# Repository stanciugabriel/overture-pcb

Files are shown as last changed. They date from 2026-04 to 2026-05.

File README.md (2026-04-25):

# Overture PCB

Overture is a custom ESP32-C6 control board designed to drive a NEMA 17 stepper motor while handling NFC reading, a small display, and physical user inputs. Everything is powered through a single USB-C Power Delivery connection.

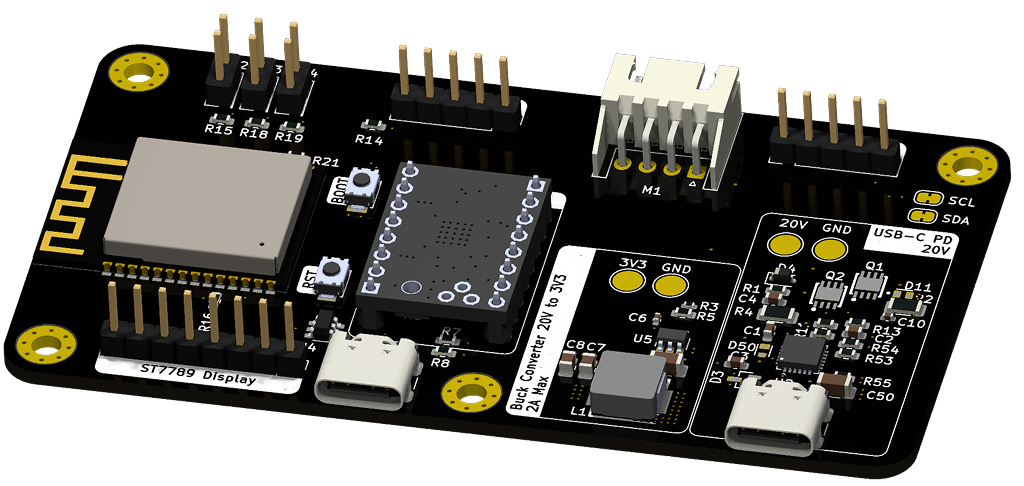
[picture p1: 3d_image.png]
3d image


## Hardware Specs

* **Microcontroller:** ESP32-C6-WROOM-1
* **Motor Driver:** TMC2208/TMC2209 setup driving a JST-XH port, sized for a NEMA 17 stepper.
* **Peripheral Headers:** Broken out pins for an ST7789 TFT screen, a PN532 NFC module, 3 push buttons, and a rotary encoder.
* **Power Delivery:** Uses an STUSB4500 PD controller to negotiate 20V directly from a USB-C wall adapter.
* **Power Regulation:** A TPS54308DDCT buck converter steps the 20V down to 3.3V (up to 2A max) to power the ESP32 and logic peripherals.
* **Programming:** Features a secondary USB-C port dedicated strictly to flashing and serial output.

## Power and Flashing

The board uses a dual USB-C port design to separate power and data. 

To power the motor and board, plug a compatible USB-C PD charger into the main power port. The STUSB4500 handles the 20V negotiation automatically. 

To flash the ESP32, use the secondary USB-C port. Note that the primary power port does not route data lines to the ESP32 and will not show up as a COM port on your machine.

## Exports

The exports folder contains all the file for production:
* hw1-bom.csv - is the Bill of Materials (formatted for JLCPCB)
* hw1-top-pos.csv - is the Components Position File for PCB-A (formatted for JLCPCB)
* Gerber_Archived.zip - has all the Gerber and Drill files needed for production

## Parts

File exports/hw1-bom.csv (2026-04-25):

Value | Reference | Footprint | LCSC
100nF | C6,C10 | Capacitor_SMD:C_0402_1005Metric | C307331
1uF | C1,C2,C3,C4 | Capacitor_SMD:C_0603_1608Metric | C5199872
33uF | C7,C8 | Capacitor_SMD:C_0805_2012Metric | C342635
6.8uF | C5 | Capacitor_SMD:C_1206_3216Metric | C92797
4.7uf | C50 | Capacitor_SMD:C_1206_3216Metric | C29823
Stepper_Motor | M1 | Connector_JST:JST_XH_S4B-XH-A_1x04_P2.50mm_Horizontal | C5361047
~ | PN532-Module1 | Connector_PinHeader_2.54mm:PinHeader_1x05_P2.54mm_Vertical
RotaryEncoder_Switch | SW1 | Connector_PinHeader_2.54mm:PinHeader_1x05_P2.54mm_Vertical
~ | ST7789-Display1 | Connector_PinHeader_2.54mm:PinHeader_1x08_P2.54mm_Vertical
SW_Back | SW2 | Connector_PinHeader_2.54mm:PinHeader_2x01_P2.54mm_Vertical
SW_Bolus | SW3 | Connector_PinHeader_2.54mm:PinHeader_2x01_P2.54mm_Vertical
SW_Settings | SW4 | Connector_PinHeader_2.54mm:PinHeader_2x01_P2.54mm_Vertical
Schottky | D4 | Diode_SMD:D_SOD-323 | C7502694
STL6P3LLH6 | Q1,Q2 | hw1_footprint:mosfetty | C49452349
ESP32-C6-WROOM-1 | U6 | hw1_footprint:ESP32-C6-WROOM-1_edit | C5366877
3.3uH | L1 | hw1_footprint:IND-SMD_L7.2-W6.6_GPSR07X0 | C5189747
STUSB4500QTR | U2 | hw1_footprint:QFN-24-1EP_4x4mm_P0.5mm_EP2.65x2.65mm | C2678061
ESDA25W | D3 | hw1_footprint:SOT65P210X110-3N | C2935152
TPS54308DDCT | U5 | hw1_footprint:SOT95P280X110-6N | C168839
SW_Push | SW5,SW6 | hw1_footprint:SW_TS-1088-AR02016 | C720477
~ | U1 | hw1_footprint:TMC2208_edit
ESDA25P35-1U1M | D11,D50 | hw1_footprint:TVS_ESDA25P35-1U1M | C1974707
~ | JP5,JP6 | Jumper:SolderJumper-2_P1.3mm_Bridged_RoundedPad1.0x1.5mm
MountingHole_Pad | H1,H2,H3,H4 | MountingHole:MountingHole_3mm_Pad_Via
USBLC6-2SC6 | U4 | Package_TO_SOT_SMD:SOT-23-6 | C7519
100k | R3 | Resistor_SMD:R_0402_1005Metric | C25741
470 | R1 | Resistor_SMD:R_0603_1608Metric | C23179
22k | R5 | Resistor_SMD:R_0603_1608Metric | C31850
10k | R6,R14,R15,R16,R18,R19 | Resistor_SMD:R_0603_1608Metric | C25804
5.1k | R7,R8 | Resistor_SMD:R_0603_1608Metric | C23186
100K | R10,R55 | Resistor_SMD:R_0603_1608Metric | C25803
22K | R11 | Resistor_SMD:R_0603_1608Metric | C31850
100 | R13 | Resistor_SMD:R_0603_1608Metric | C22775
4.7k | R21 | Resistor_SMD:R_0603_1608Metric | C23162
100k | R53,R54 | Resistor_SMD:R_0603_1608Metric | C25803
1k | R2,R4 | Resistor_SMD:R_1206_3216Metric | C4410
TestPoint | TP1,TP4,TP_3V3,TP_20V1 | TestPoint:TestPoint_Pad_D3.0mm
USB_C_Receptacle_USB2.0_16P | J1,J2 | USB_C_Receptacle_GCT_USB4105-xx-A_16P_TopMnt_Horizontal | C2765186

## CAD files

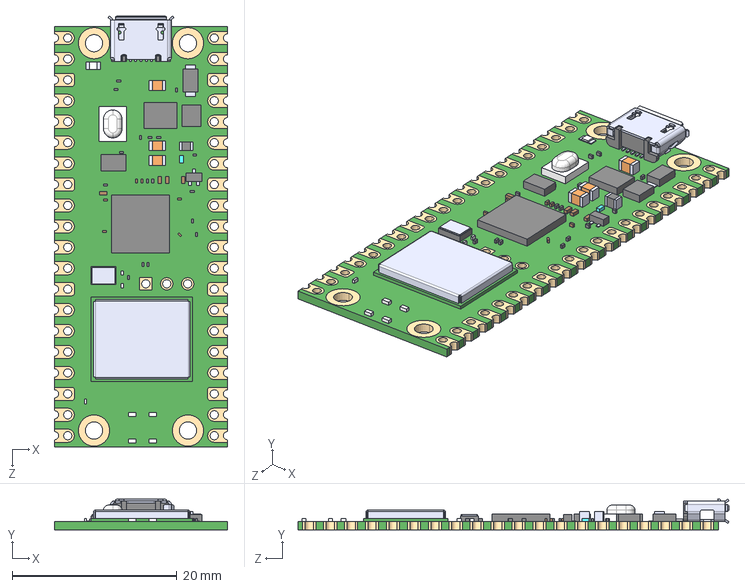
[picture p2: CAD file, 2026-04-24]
step-files/RASPBERRY_PI_PICO_W.step
21.0 x 3.73 x 52.3 mm

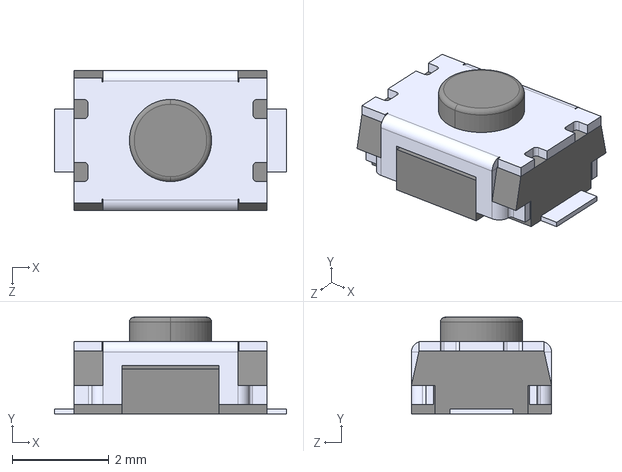
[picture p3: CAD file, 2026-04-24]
step-files/TS-1088-AR02016.step
4.80 x 2.00 x 2.90 mm

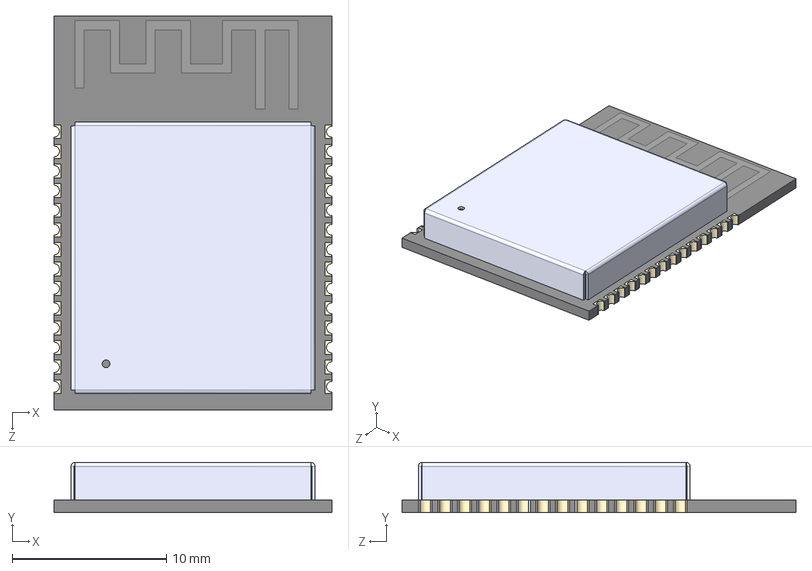
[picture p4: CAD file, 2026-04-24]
step-files/ESP32-C6-WROOM-1-N8.step
18.0 x 3.25 x 25.5 mm

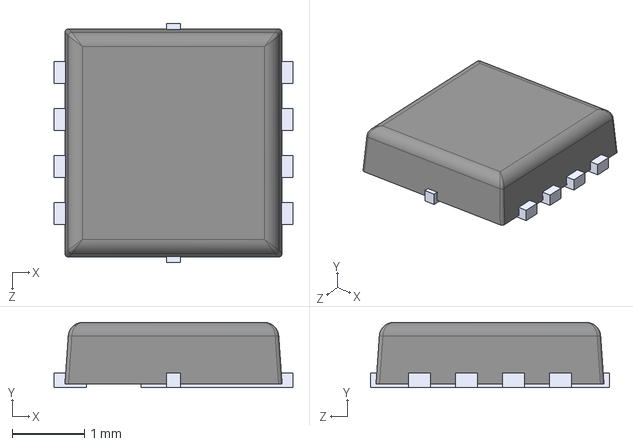
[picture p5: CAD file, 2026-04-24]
step-files/STL6P3LLH6.step
3.30 x 0.9 x 3.30 mm

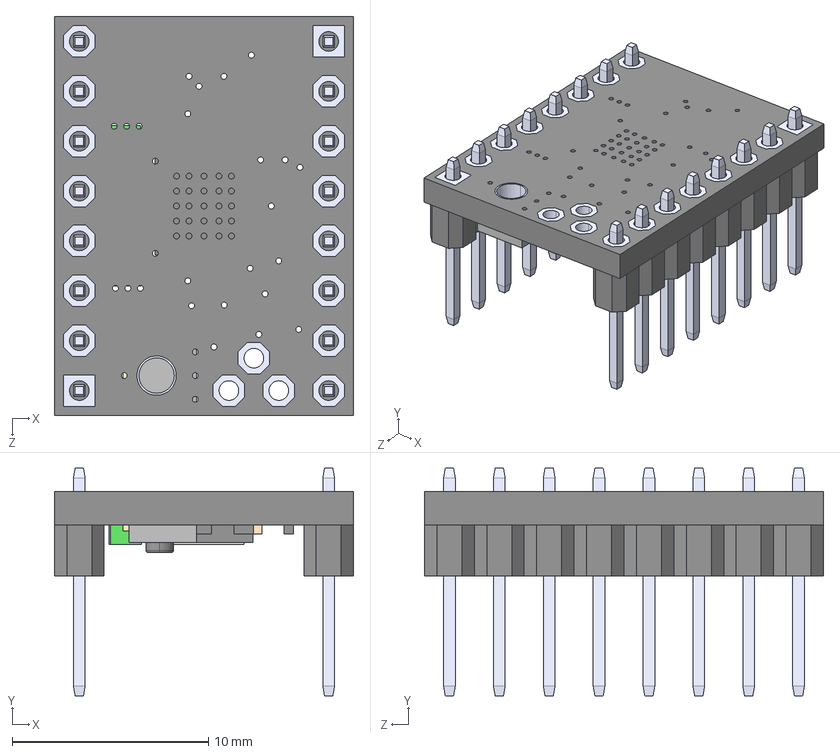
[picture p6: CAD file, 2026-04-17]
step-files/TMC2209_SILENTSTEPSTICK.step
15.2 x 11.6 x 20.3 mm

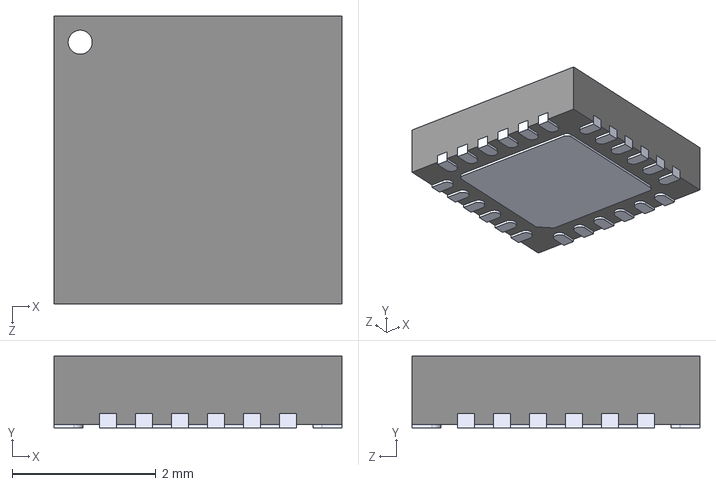
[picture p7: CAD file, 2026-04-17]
step-files/STUSB4500QTR.step
4.00 x 1.00 x 4.00 mm

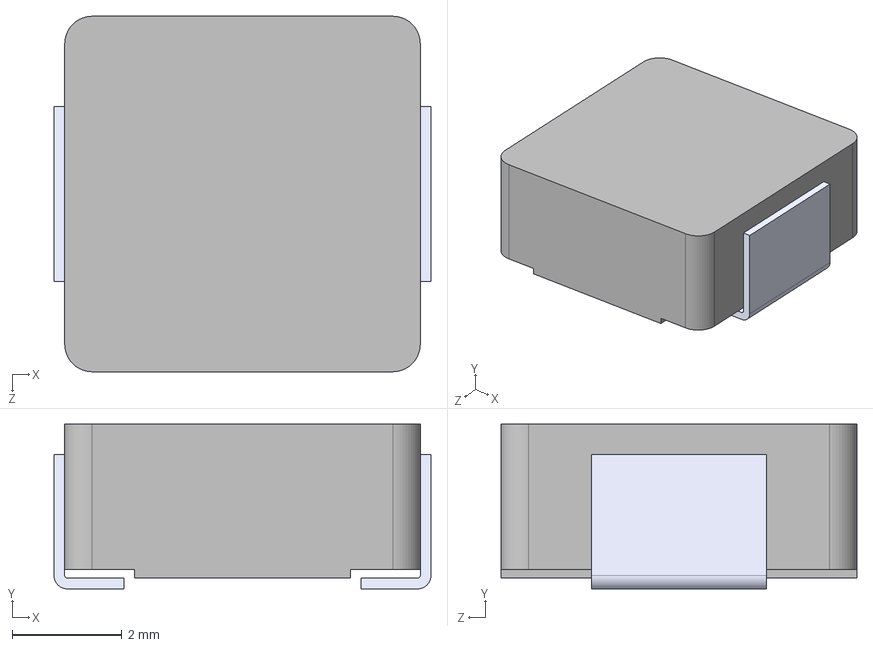
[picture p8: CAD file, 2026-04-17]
step-files/IHLP2525CZER8R2M01.step
6.86 x 3.00 x 6.47 mm

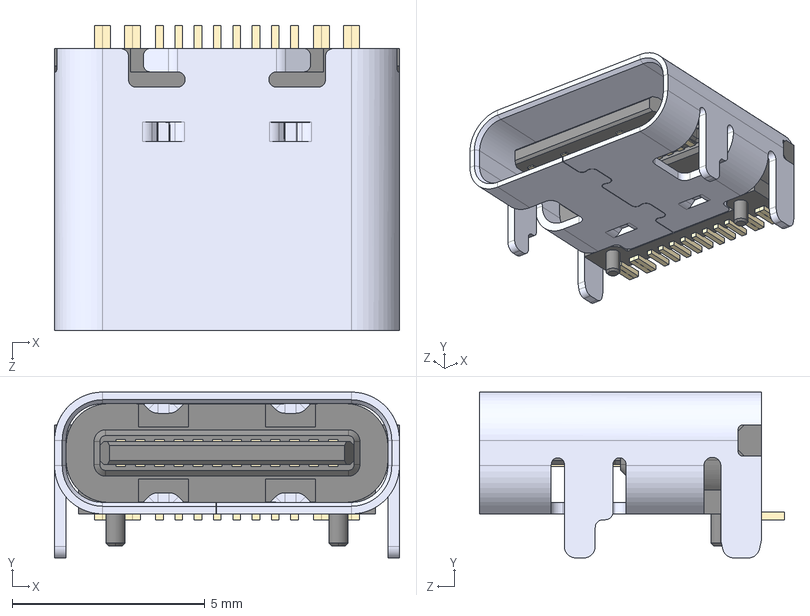
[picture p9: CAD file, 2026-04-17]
step-files/TYPE-C-31-M-12.step
8.94 x 4.30 x 7.90 mm

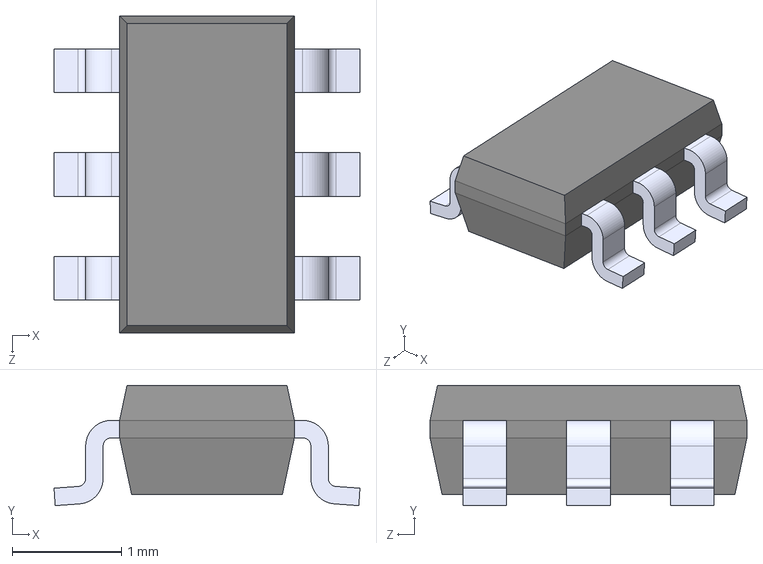
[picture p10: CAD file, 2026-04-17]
step-files/TPS54308DDCT.step
2.80 x 1.10 x 2.90 mm

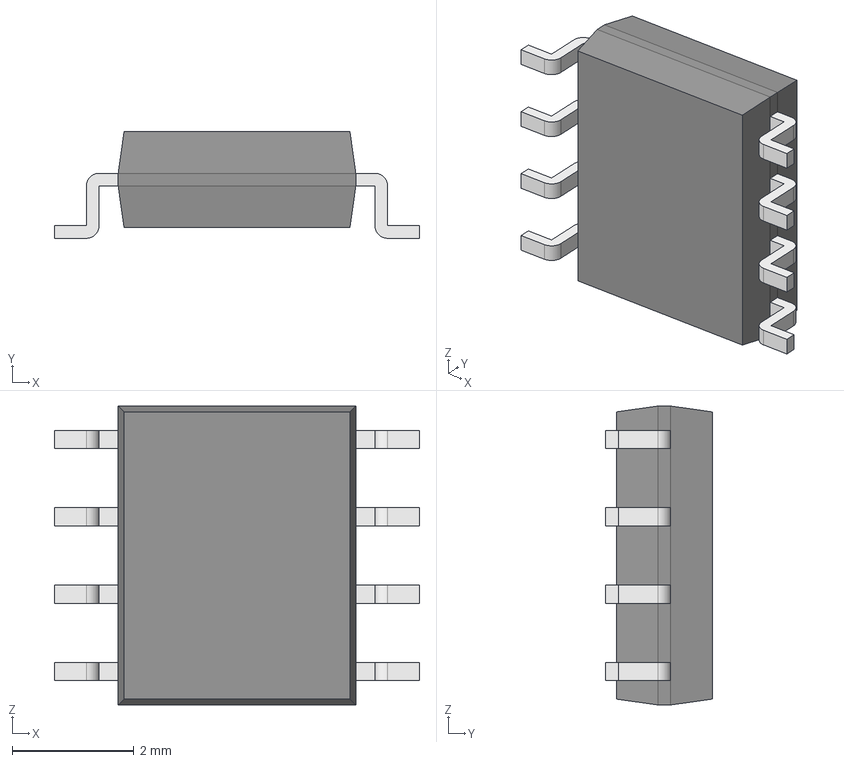
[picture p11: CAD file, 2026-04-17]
step-files/TPS54331DR.step
5.99 x 1.75 x 4.91 mm
Body001 (Mirror #1) x 4
XY-plane x 12
X-axis x 12

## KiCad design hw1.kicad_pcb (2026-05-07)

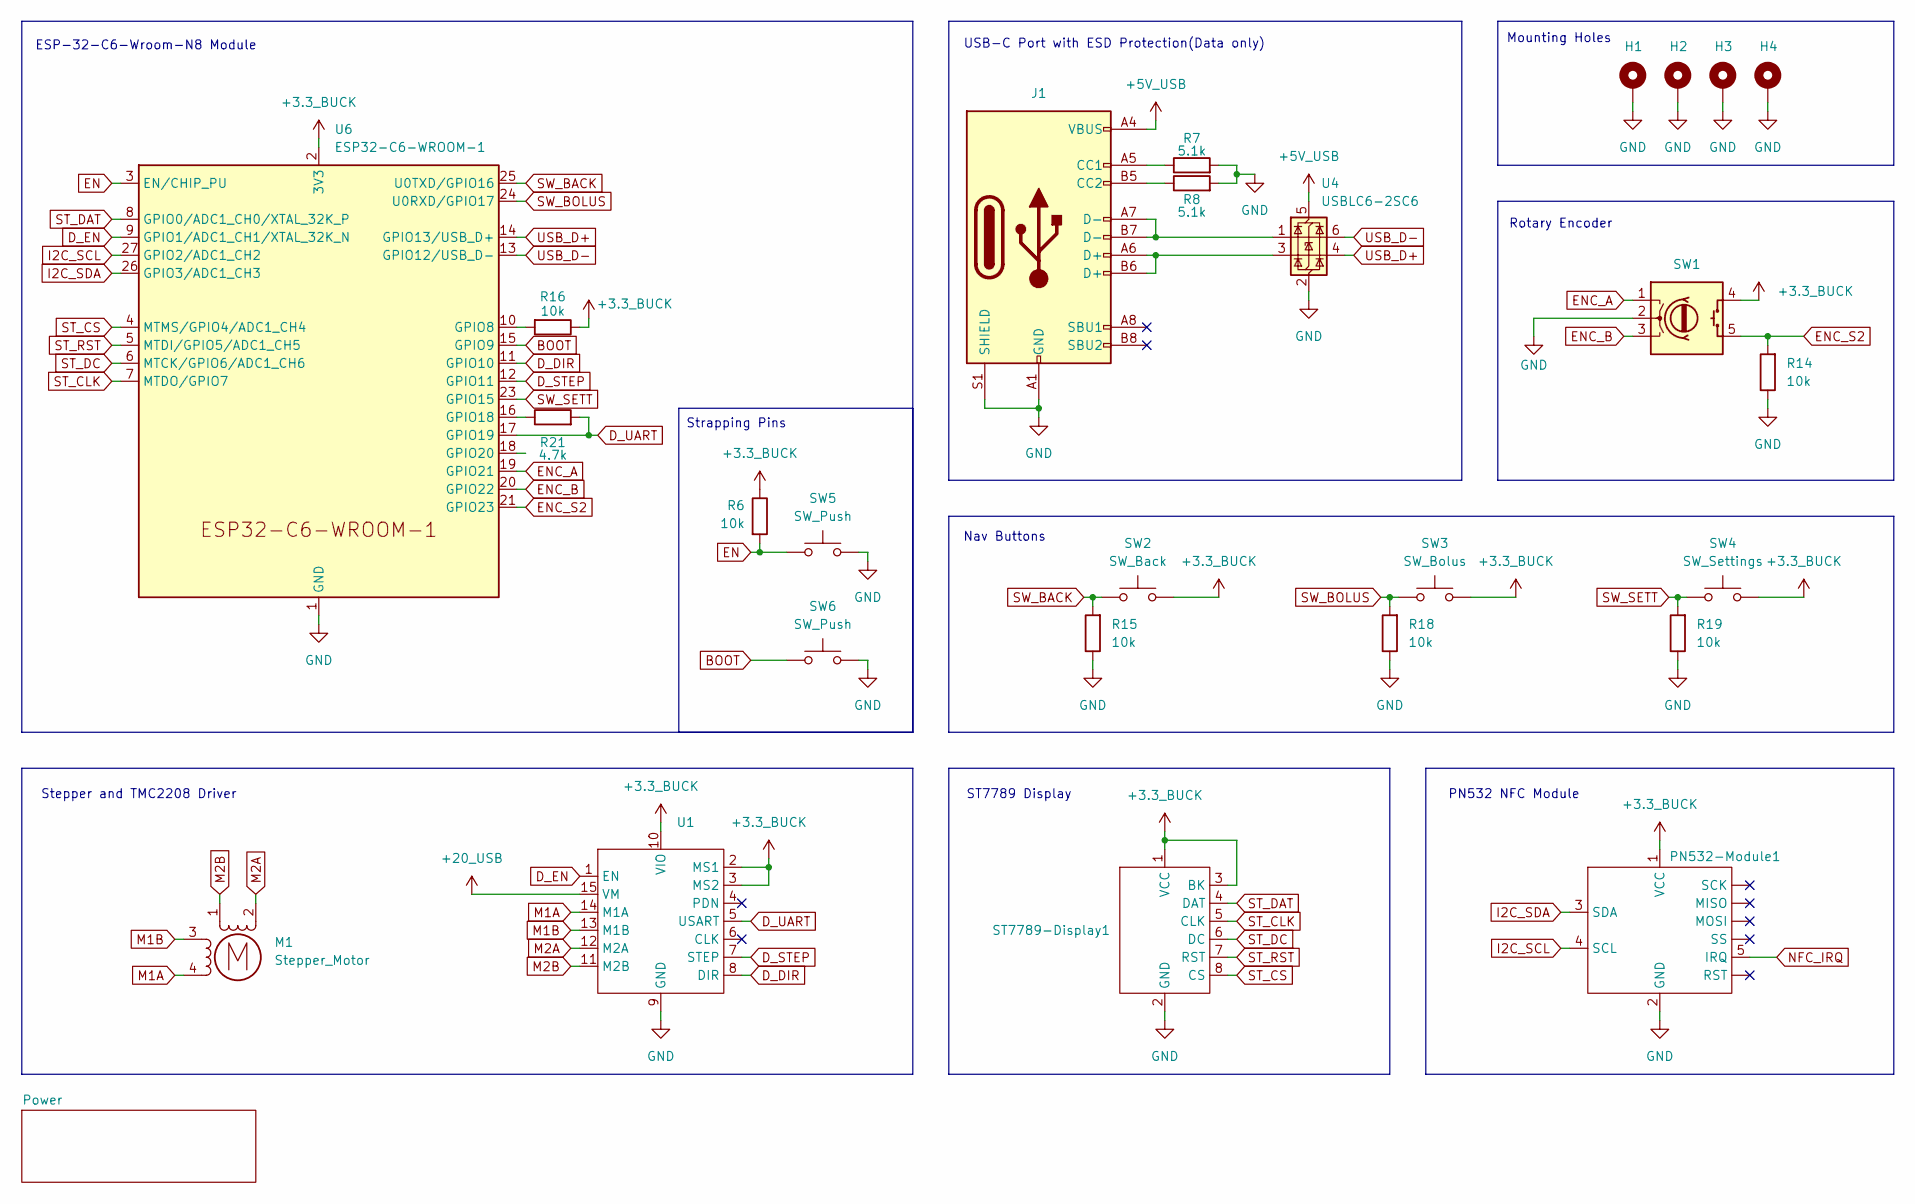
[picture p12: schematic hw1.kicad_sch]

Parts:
H1, H2, H3, H4: MountingHole_Pad; MountingHole_3mm_Pad_Via
J1: USB_C_Receptacle_USB2.0_16P; USB_C_Receptacle_GCT_USB4105-xx-A_16P_TopMnt_Horizontal; LCSC C2765186
M1: Stepper_Motor; JST_XH_S4B-XH-A_1x04_P2.50mm_Horizontal; LCSC C5361047
PN532-Module1: PinHeader_1x05_P2.54mm_Vertical
R6, R14, R15, R16, R18, R19: 10k; R_0603_1608Metric; LCSC C25804
R7, R8: 5.1k; R_0603_1608Metric; LCSC C23186
R21: 4.7k; R_0603_1608Metric; LCSC C23162
ST7789-Display1: PinHeader_1x08_P2.54mm_Vertical
SW1: RotaryEncoder_Switch; PinHeader_1x05_P2.54mm_Vertical
SW2: SW_Back; PinHeader_2x01_P2.54mm_Vertical
SW3: SW_Bolus; PinHeader_2x01_P2.54mm_Vertical
SW4: SW_Settings; PinHeader_2x01_P2.54mm_Vertical
SW5, SW6: SW_Push; SW_TS-1088-AR02016; LCSC C720477
U1: TMC2208_edit
U4: USBLC6-2SC6; SOT-23-6; LCSC C7519
U6: ESP32-C6-WROOM-1; ESP32-C6-WROOM-1_edit; LCSC C5366877

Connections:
+3.3_BUCK: PN532-Module1.1 (VCC), R6.1, R16.1, ST7789-Display1.1 (VCC), ST7789-Display1.3 (BK), SW1.4 (S1), SW2.2, SW3.2, SW4.2, U1.2 (MS1), U1.3 (MS2), U1.10 (VIO), U6.2 (3V3); also elsewhere on the board
+5V_USB: J1.A4 (VBUS), J1.A9 (VBUS), J1.B4 (VBUS), J1.B9 (VBUS), U4.5 (VBUS)
+20_USB: U1.15 (VM); also elsewhere on the board
BOOT: SW6.1, U6.15 (GPIO9)
D_DIR: U1.8 (DIR), U6.11 (GPIO10)
D_EN: U1.1 (EN), U6.9 (GPIO1/ADC1_CH1/XTAL_32K_N)
D_STEP: U1.7 (STEP), U6.12 (GPIO11)
D_UART: R21.2, U1.5 (USART), U6.17 (GPIO19)
EN: R6.2, SW5.1, U6.3 (EN/CHIP_PU)
ENC_A: SW1.1 (A), U6.19 (GPIO21)
ENC_B: SW1.3 (B), U6.20 (GPIO22)
ENC_S2: R14.2, SW1.5 (S2), U6.21 (GPIO23)
GND: H1.1, H2.1, H3.1, H4.1, J1.A1 (GND), J1.A12 (GND), J1.B1 (GND), J1.B12 (GND), J1.S1 (SHIELD), PN532-Module1.2 (GND), R7.2, R8.2, R14.1, R15.1, R18.1, R19.1, ST7789-Display1.2 (GND), SW1.2 (C), SW5.2, SW6.2, U1.9 (GND), U4.2 (GND), U6.1 (GND), U6.28 (GND), U6.29 (GND); also elsewhere on the board
I2C_SCL: PN532-Module1.4 (SCL), U6.27 (GPIO2/ADC1_CH2); also elsewhere on the board
I2C_SDA: PN532-Module1.3 (SDA), U6.26 (GPIO3/ADC1_CH3); also elsewhere on the board
M1A: M1.4, U1.14 (M1A)
M1B: M1.3, U1.13 (M1B)
M2A: M1.2 (-), U1.12 (M2A)
M2B: M1.1, U1.11 (M2B)
NFC_IRQ: PN532-Module1.5 (IRQ)
unnamed: J1.A5 (CC1), R7.1
unnamed: J1.B5 (CC2), R8.1
unnamed: J1.A6 (D+), J1.B6 (D+), U4.3 (I/O2)
unnamed: J1.A7 (D-), J1.B7 (D-), U4.1 (I/O1)
unnamed: R16.2, U6.10 (GPIO8)
unnamed: R21.1, U6.16 (GPIO18)
ST_CLK: ST7789-Display1.5 (CLK), U6.7 (MTDO/GPIO7)
ST_CS: ST7789-Display1.8 (CS), U6.4 (MTMS/GPIO4/ADC1_CH4)
ST_DAT: ST7789-Display1.4 (DAT), U6.8 (GPIO0/ADC1_CH0/XTAL_32K_P)
ST_DC: ST7789-Display1.6 (DC), U6.6 (MTCK/GPIO6/ADC1_CH6)
ST_RST: ST7789-Display1.7 (RST), U6.5 (MTDI/GPIO5/ADC1_CH5)
SW_BACK: R15.2, SW2.1, U6.25 (U0TXD/GPIO16)
SW_BOLUS: R18.2, SW3.1, U6.24 (U0RXD/GPIO17)
SW_SETT: R19.2, SW4.1, U6.23 (GPIO15)
USB_D+: U4.4 (I/O2), U6.14 (GPIO13/USB_D+)
USB_D-: U4.6 (I/O1), U6.13 (GPIO12/USB_D-)

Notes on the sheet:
USB-C Port with ESD Protection(Data only)
Nav Buttons
ESP-32-C6-Wroom-N8 Module
ST7789 Display
Rotary Encoder
PN532 NFC Module
Mounting Holes
Strapping Pins
Stepper and TMC2208 Driver

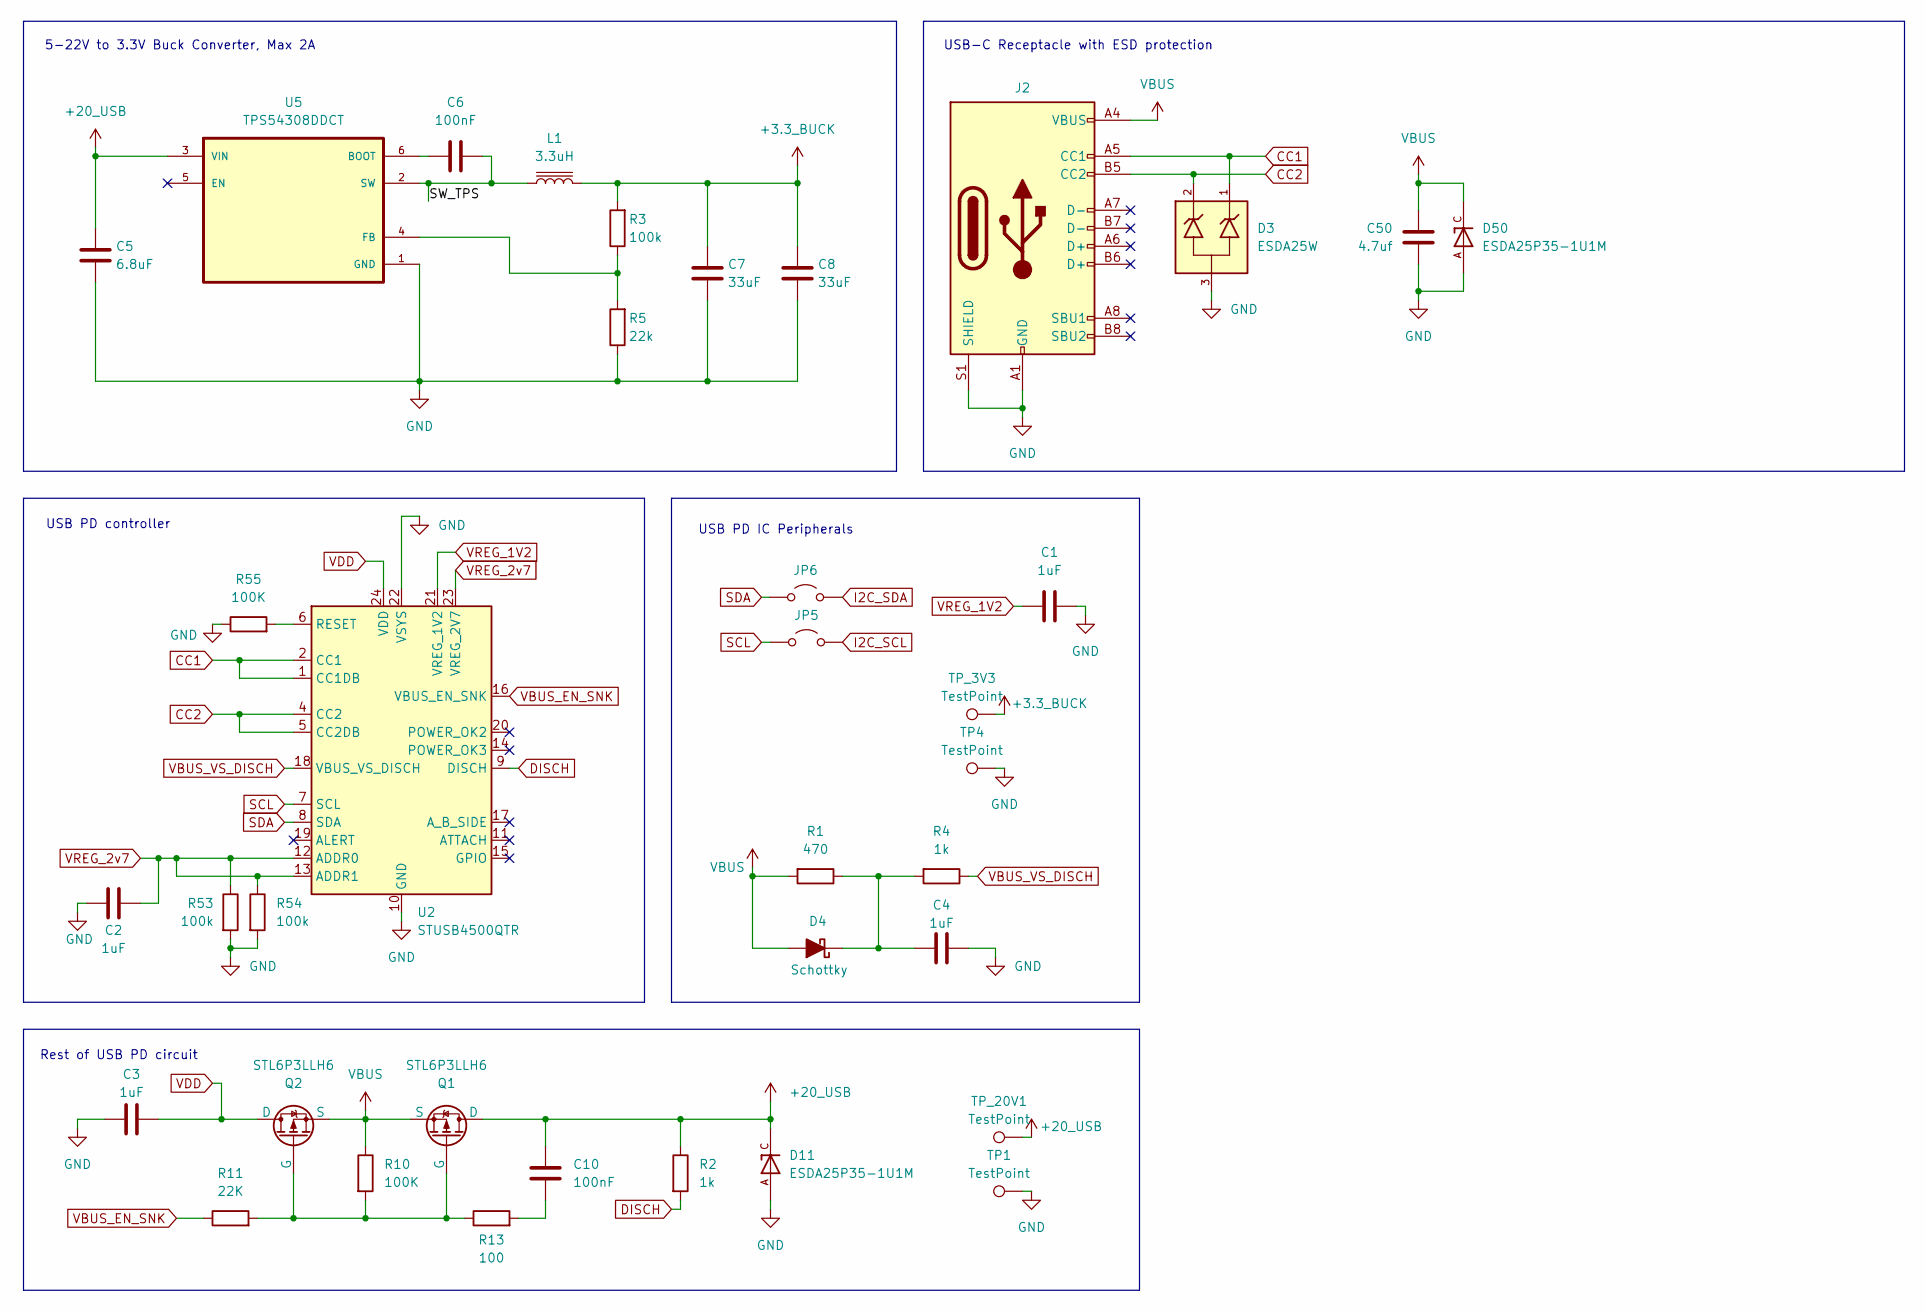
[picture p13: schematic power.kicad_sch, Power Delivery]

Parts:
C1, C2, C3, C4: 1uF; C_0603_1608Metric; LCSC C5199872
C5: 6.8uF; C_1206_3216Metric; LCSC C92797
C6, C10: 100nF; C_0402_1005Metric; LCSC C307331
C7, C8: 33uF; C_0805_2012Metric; LCSC C342635
C50: 4.7uf; C_1206_3216Metric; LCSC C29823
D3: ESDA25W; SOT65P210X110-3N; PARTREV 2; LCSC C2935152
D4: Schottky; D_SOD-323; LCSC C7502694
D11, D50: ESDA25P35-1U1M; TVS_ESDA25P35-1U1M; PARTREV 2; LCSC C1974707
J2: USB_C_Receptacle_USB2.0_16P; USB_C_Receptacle_GCT_USB4105-xx-A_16P_TopMnt_Horizontal; LCSC C2765186
JP5, JP6: SolderJumper-2_P1.3mm_Bridged_RoundedPad1.0x1.5mm
L1: 3.3uH; IND-SMD_L7.2-W6.6_GPSR07X0; LCSC C5189747
Q1, Q2: STL6P3LLH6; mosfetty; LCSC C49452349
R1: 470; R_0603_1608Metric; LCSC C23179
R2, R4: 1k; R_1206_3216Metric; LCSC C4410
R3: 100k; R_0402_1005Metric; LCSC C25741
R5: 22k; R_0603_1608Metric; LCSC C31850
R10, R55: 100K; R_0603_1608Metric; LCSC C25803
R11: 22K; R_0603_1608Metric; LCSC C31850
R13: 100; R_0603_1608Metric; LCSC C22775
R53, R54: 100k; R_0603_1608Metric; LCSC C25803
TP1, TP4: TestPoint; TestPoint_Pad_D3.0mm
TP_3V3, TP_20V1: TestPoint; TestPoint_Pad_D3.0mm
U2: STUSB4500QTR; QFN-24-1EP_4x4mm_P0.5mm_EP2.65x2.65mm; LCSC C2678061
U5: TPS54308DDCT; SOT95P280X110-6N; DigiKey_Part_Number 296-47881-1-ND

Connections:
+3.3_BUCK: C7.2, C8.2, L1.2, R3.2, TP_3V3.1; also elsewhere on the board
+20_USB: C5.2, C10.1, D11.C, Q1.1 (D), R2.1, TP_20V1.1, U5.3 (VIN); also elsewhere on the board
/Power/SW_TPS: C6.1, L1.1, U5.2 (SW)
CC1: D3.1, J2.A5 (CC1), U2.1 (CC1DB), U2.2 (CC1)
CC2: D3.2, J2.B5 (CC2), U2.4 (CC2), U2.5 (CC2DB)
DISCH: R2.2, U2.9 (DISCH)
GND: C1.2, C2.2, C3.1, C4.2, C5.1, C7.1, C8.1, C50.2, D3.3, D11.A, D50.A, J2.A1 (GND), J2.A12 (GND), J2.B1 (GND), J2.B12 (GND), J2.S1 (SHIELD), R5.1, R53.2, R54.2, R55.1, TP1.1, TP4.1, U2.10 (GND), U2.22 (VSYS), U2.25 (GND), U5.1 (GND); also elsewhere on the board
I2C_SCL: JP5.2 (B); also elsewhere on the board
I2C_SDA: JP6.2 (B); also elsewhere on the board
unnamed: C10.2, R13.2
unnamed: C4.1, D4.1 (K), R1.1, R4.2
unnamed: Q1.2 (G), Q2.2 (G), R10.2, R11.2, R13.1
unnamed: R55.2, U2.6 (RESET)
unnamed: C6.2, U5.6 (BOOT)
unnamed: R3.1, R5.2, U5.4 (FB)
SCL: JP5.1 (A), U2.7 (SCL)
SDA: JP6.1 (A), U2.8 (SDA)
VBUS: C50.1, D4.2 (A), D50.C, J2.A4 (VBUS), J2.A9 (VBUS), J2.B4 (VBUS), J2.B9 (VBUS), Q1.3 (S), Q2.3 (S), R1.2, R10.1
VBUS_EN_SNK: R11.1, U2.16 (VBUS_EN_SNK)
VBUS_VS_DISCH: R4.1, U2.18 (VBUS_VS_DISCH)
VDD: C3.2, Q2.1 (D), U2.24 (VDD)
VREG_1V2: C1.1, U2.21 (VREG_1V2)
VREG_2v7: C2.1, R53.1, R54.1, U2.12 (ADDR0), U2.13 (ADDR1), U2.23 (VREG_2V7)

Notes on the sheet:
USB PD controller
Rest of USB PD circuit
USB-C Receptacle with ESD protection
USB PD IC Peripherals
5-22V to 3.3V Buck Converter, Max 2A

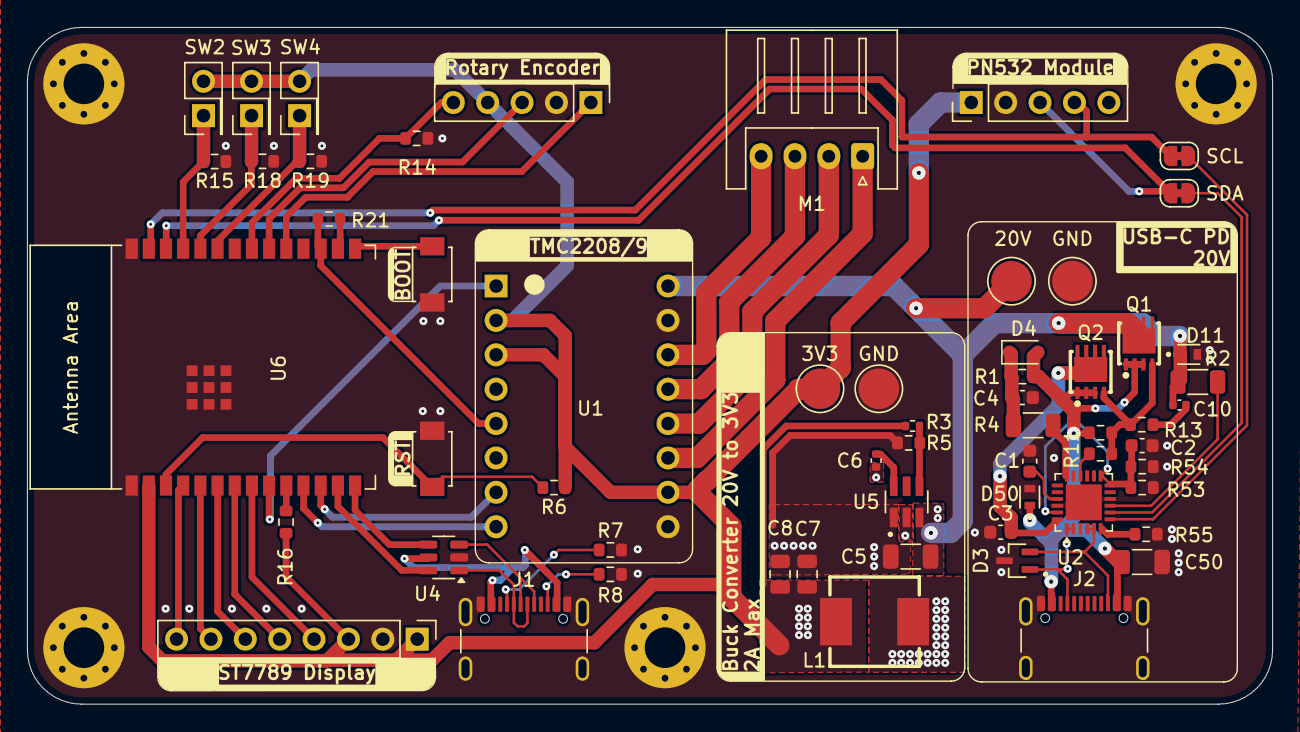
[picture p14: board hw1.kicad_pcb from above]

Board: 2 copper layers, 92.0 x 50.0 mm, 63 parts (0 on the bottom side), 53 nets.

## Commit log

2026-04-17 Finalized the first version, and rearranged file structure
    [IHLP2525CZER8R2M01.step, STUSB4500QTR.step, TMC2209_SILENTSTEPSTICK.step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]
2026-04-17 Added thicker traces for the whole MCU part. Still need to fix some DRC errors related to the XIAO's castellated pins.
    [hw1.kicad_pcb, hw1.kicad_sch, power.kicad_sch]
2026-04-21 Re-arranged some traces
    [bom.csv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]
2026-04-24 Finalized PCB design, still have to tweak some stuff though
    [ESP32-C6-WROOM-1-N8.step, RASPBERRY_PI_PICO_W.step, STL6P3LLH6.step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]
2026-04-25 Added LCSC codes, swapped extended components for basic ones, fixed labels and tidied schematics.
    [bom.csv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]
2026-05-07 Finalised design, sent PCB to manufacturing
    [BOM-hw1.csv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]
